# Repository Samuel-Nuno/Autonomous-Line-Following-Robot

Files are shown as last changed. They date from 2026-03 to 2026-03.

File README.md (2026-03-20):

# Autonomous-Line-Following-Robot
**Team Members:** Samuel Nuno, Bruce Berg

## Project Summary
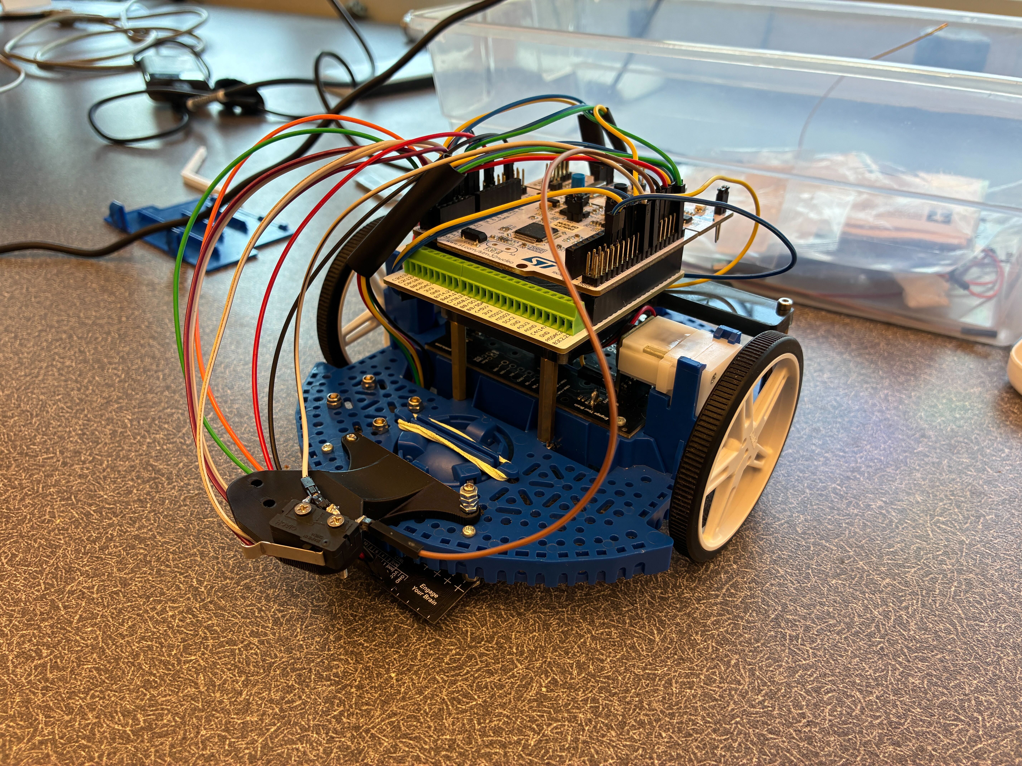
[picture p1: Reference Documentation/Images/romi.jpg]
Project Summary Image


This project documents our ME 405 [Romi](https://www.pololu.com/category/202/romi-chassis-and-accessories) final project, in which we developed a differential-drive robot capable of autonomous line following with closed-loop wheel control, line position estimation, and obstacle-triggered recovery behavior. The goal of the project was to create a robot that could reliably follow the printed course at speed while using organized, reproducible software and clear system documentation.

## Project Objective
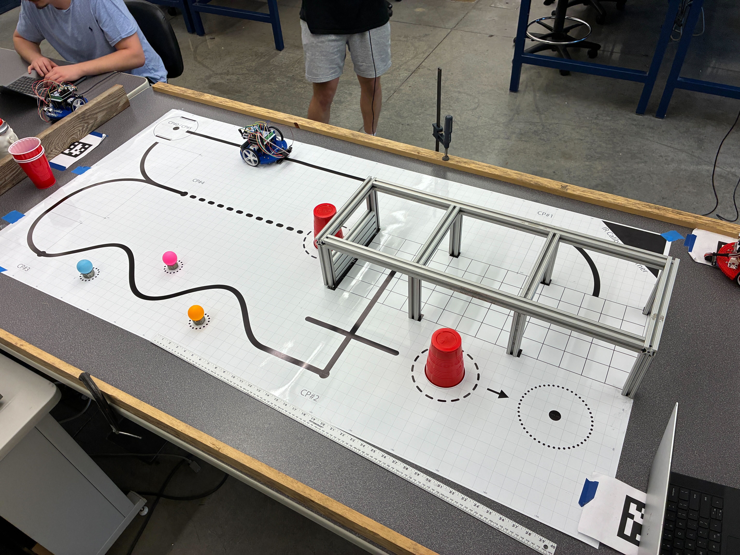
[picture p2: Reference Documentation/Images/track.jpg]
Project Objective Image


### Course Description
The course consists of four checkpoints. The starting point to the first checkpoint has a long straightaway where speed should be optimized. After Checkpoint 1, there is a right hand 90 degree turn into the garage, where there is no line to follow. Romi must navigate to the wall of the garage and, using a bump detection method, turn left to get back on the line. After the garage exit, there is a line perpendicular to the path out of the garage on which Romi may choose to turn left and bump a cup out of a position to reduce the overall time by 4 seconds. After the cup, Checkpoint 2 is reached. After Checkpoint 2, there is a slalom section, where Romi must make tight turns and avoid knocking ping pong balls out of position. If a ping pong ball is hit, a time penalty of 2 seconds is applied for each bumped ping pong ball. After the slalom section, Checkpoint 3 is reached. After Checkpoint 3, there is a large right hand turn into a cusp. At the end of the cusp, there is Checkpoint 4. After Checkpoint 4, there is a dotted line leading to an upsidedown cup, which, if knocked out of position, reduces the total time by 4 seconds. At the cusp, there is a turn that requires Romi to turn around and turn to the right to reach the finish line and complete the course.

### Our Approach to the Course
Our robot was designed to complete a line following time trial course by combining encoder based wheel feedback, analog line sensing, and task-based control software. The system was structured to prioritize repeatable behavior and robustness rather than relying on open-loop tuning alone.

We elected to avoid any of the additional bonus cups, since we evaluated that they would take too much time and development time to do reliably and fast enough to be worth it. We use our line following and specific events in our closed loop file that allow us to use line following along with hardcoded movements for the more dynamic movements which are triggered by events where the line is lost.

## Mechanical and Electrical Design
The platform is based on the Pololu Romi differential-drive chassis. The robot uses two independently driven wheels, each with its own motor and encoder feedback. In our preliminary design work, we identified several key chassis parameters that informed our control and sensing decisions, including a wheel radius of 35 mm and a track width of 141 mm.

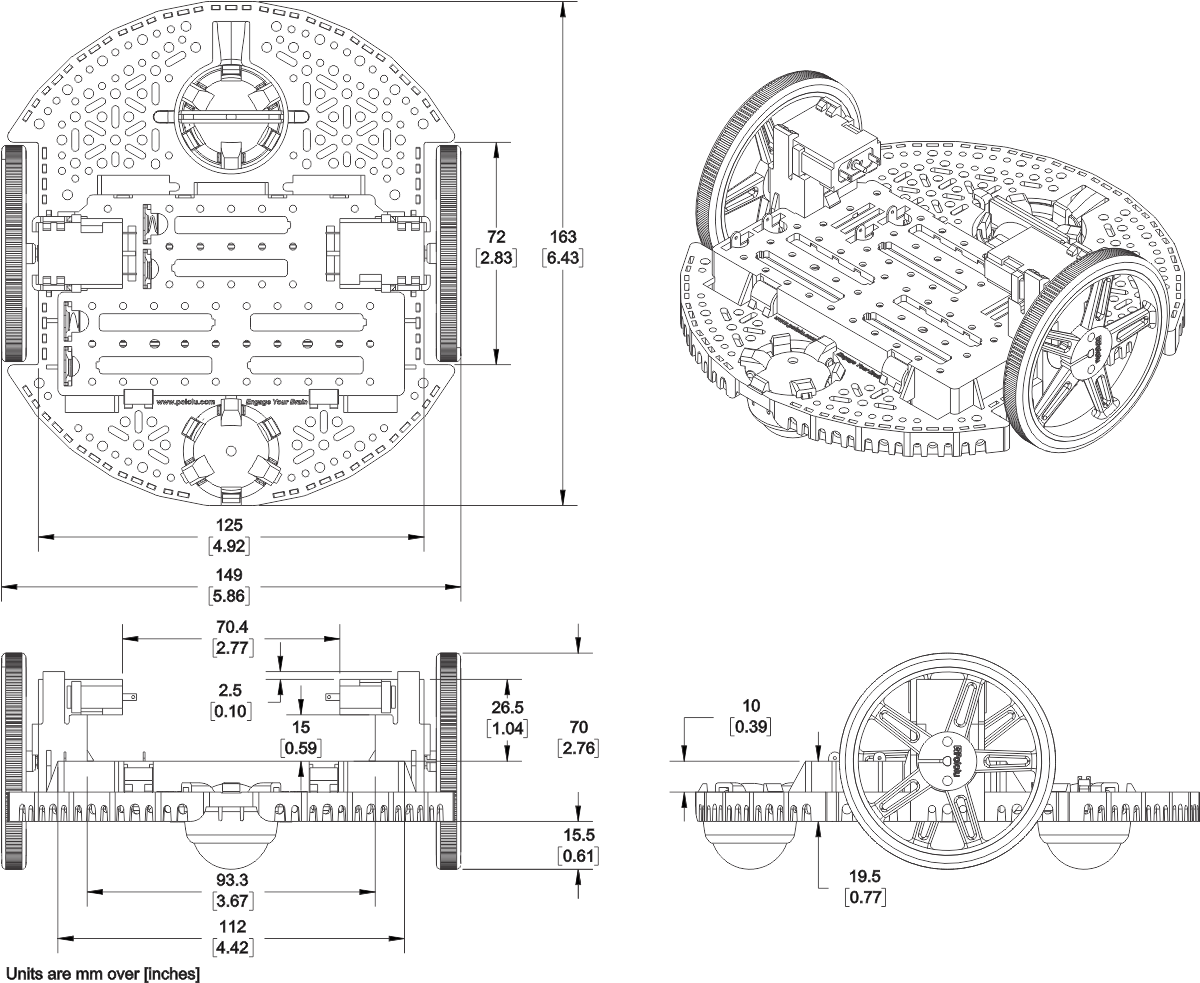
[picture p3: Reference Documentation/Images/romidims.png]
Romi Schematic


The electrical system includes:
- Two DC drive motors
- Wheel encoders for each side
- An STM32 microcontroller running MicroPython
- A Pololu QTR-8A analog reflectance sensor array for line following
- A bump sensor implemented as a single limit switch
- Motor driver outputs using PWM and direction pins

### Pinout Diagram
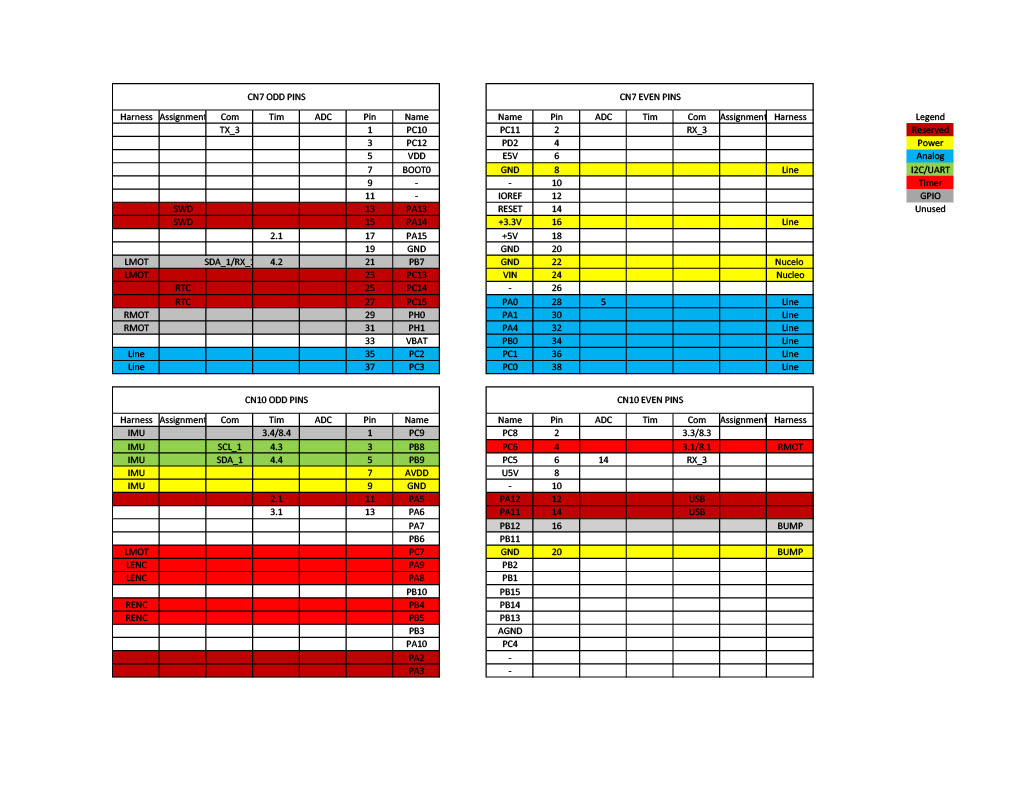
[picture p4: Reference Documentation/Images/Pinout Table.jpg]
Pinout Diagram


### Wiring Harnesses
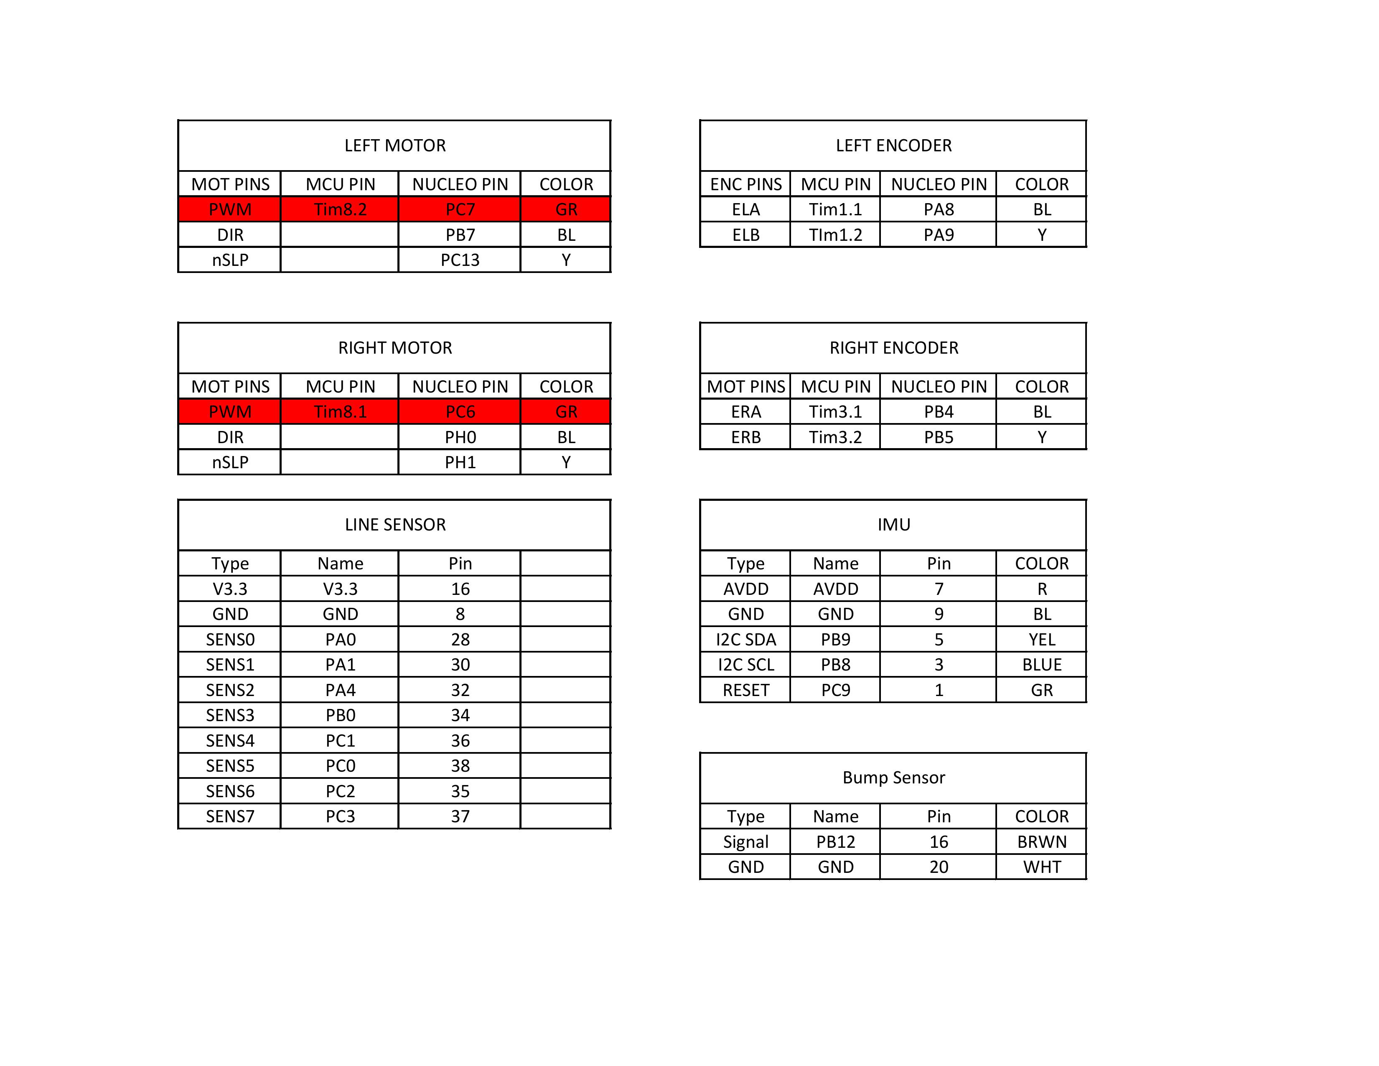
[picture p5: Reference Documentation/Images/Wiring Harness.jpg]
Harness Diagram


### Motor and Encoder Interface
Each motor is controlled by a PWM signal and a direction pin. Encoder feedback is used to estimate wheel speed and wheel position continuously.

## Sensors Used

### [Wheel Encoders](https://www.pololu.com/product/3675)
We used one quadrature encoder per wheel to estimate wheel position and velocity. In software, encoder counts are converted into wheel speed in mm/s.

### [Line Sensor Array](https://www.pololu.com/product/4248)
We selected an 8-channel analog Pololu QTR-MD-08A reflectance sensor array. An analog sensor array was chosen because it provides continuous reflectance measurements across all channels, allowing for more precise line position estimation and smoother control compared to digital threshold-based sensors.

The line sensor is calibrated on both white background and black line surfaces. After calibration, the readings from each channel are normalized, and a weighted centroid is computed (ranging from 0 to 7) to estimate the position of the line relative to the sensor array.

### [Bump Sensor](https://www.pololu.com/product/1405)
The bump sensor is implemented as a **single limit switch**. This provides a simple and reliable method of detecting contact with obstacles or walls, allowing the robot to trigger recovery behavior when pressed.

The bump sensor was mounted with a custom 3D printed part. The file can be found [here.](https://github.com/Samuel-Nuno/Autonomous-Line-Following-Robot/blob/main/Reference%20Documentation/Bump%20Sensor%20Mount.step)

### [IMU (Inertial Measurement Unit)](https://learn.adafruit.com/adafruit-bno055-absolute-orientation-sensor/overview)

The robot uses a BNO055 IMU to measure orientation, specifically the robot’s heading (yaw angle). The IMU provides absolute heading information, which allows the robot to understand its orientation relative to its starting direction.

Heading data is used primarily during recovery and maneuvering behaviors rather than continuous line following. When the robot performs actions such as turning 90 degrees or reorienting itself after losing the line, the IMU provides feedback to ensure accurate and repeatable rotations.

By monitoring the change in heading, the robot can:
- execute precise turns (e.g., 90° rotations),
- maintain consistent orientation during recovery sequences,
- and avoid relying solely on time-based or open-loop turning.

Using the IMU improves accuracy compared to open-loop turning because the robot can directly measure how far it has rotated rather than estimating based on motor commands alone.

## Software Architecture
The software is organized as a cooperative multitasking system using generators, scheduled by a priority-based task scheduler. Shared variables and queues are used for communication between tasks.

A thorough description of each file can be found in the Source Files section [here](https://github.com/Samuel-Nuno/Autonomous-Line-Following-Robot/tree/main/Source%20Code).

### Main software modules
- `main.py` initializes hardware, shares, queues, and tasks
- `cotask.py` implements cooperative task scheduling
- `task_share.py` implements inter-task shared data and queues
- `left_drive_system.py` and `right_drive_system.py` handle each motor/encoder pair
- `ClosedLoop.py` performs wheel PI control and line-following logic
- `task_line_sensor.py` reads the line sensor
- `linesensor.py` performs calibration, normalization, and centroid calculation
- `task_bump.py` handles bump detection
- `task_user.py` provides a serial tuning and diagnostics interface

## Control Strategy

### Closed-Loop Wheel Control
The robot uses PI control for left and right wheel velocity. Each wheel has a setpoint and measured velocity, and the controller computes motor effort from the wheel-speed error.

### Line Following
The line-following controller computes a centroid from the 8-sensor array, with the center target near sensor index 4. The line-following error is the difference between the measured centroid and the desired center.

The controller applies **PI control to the line-following error**, which allows smooth and continuous steering adjustments rather than abrupt corrections. A steering correction is applied by adjusting the left and right wheel velocities around a forward base speed.

This means:
- if the line appears to the left, the robot steers left,
- if the line appears to the right, the robot steers right,
- and if the line is centered, both wheels run at nearly equal speed.

## Lost-Line and Recovery Behavior
If the line sensor loses the line for several consecutive cycles, the robot begins a scripted recovery sequence. This sequence includes:
1. moving forward to square up,
2. moving farther into the garage area,
3. making a 90-degree right turn,
4. driving forward with encoder-based straightening,
5. then rotating left until the line is found again.

## Important Math and Parameters
Some important geometric and sensing values used in the project are:

- Wheel radius: **35 mm**
- Wheel diameter: **70 mm**
- Track width: **141 mm**
- Encoder resolution: **about 1430 to 1437 counts/rev**

A critical parameter in our implementation is the **conversion between encoder ticks and physical distance**. The relationship between encoder counts and linear distance is hard-coded in the software. This conversion factor determines how encoder measurements are translated into real-world units such as mm/s.

Because this value is fixed in the code, accuracy in the encoder ticks-per-unit-length conversion is essential. Any error in this parameter directly affects velocity estimation, distance tracking, and overall control performance.

## Video Demonstration
[Click Here](https://youtube.com/shorts/2tvsYlAGBHo?feature=share)

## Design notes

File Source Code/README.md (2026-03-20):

# ME405 Romi Robot Control System

## High Level Overview
This project implements a cooperative multitasking control system for a Romi robot using MicroPython. The robot uses multiple concurrent tasks to read sensors, control both motors, follow a line, and interact with the user through a serial interface.

At a high level, the system works as follows:
- The **main file** creates all shares, queues, and task objects
- The **drive system tasks** read encoders and apply motor effort
- The **closed loop task** performs PI velocity control and line-following logic
- The **line sensor task** computes the line centroid
- The **bump task** detects physical contact with an obstacle
- The **IMU heading task** reads robot heading and yaw rate
- The **user task** provides a serial command interface for tuning and testing
- The **ME405 cotask/task_share libraries** handle task scheduling and safe inter-task communication

This design separates sensing, control, and user interaction into modular finite state machines that communicate through shared variables and queues.

---

## Task Diagram
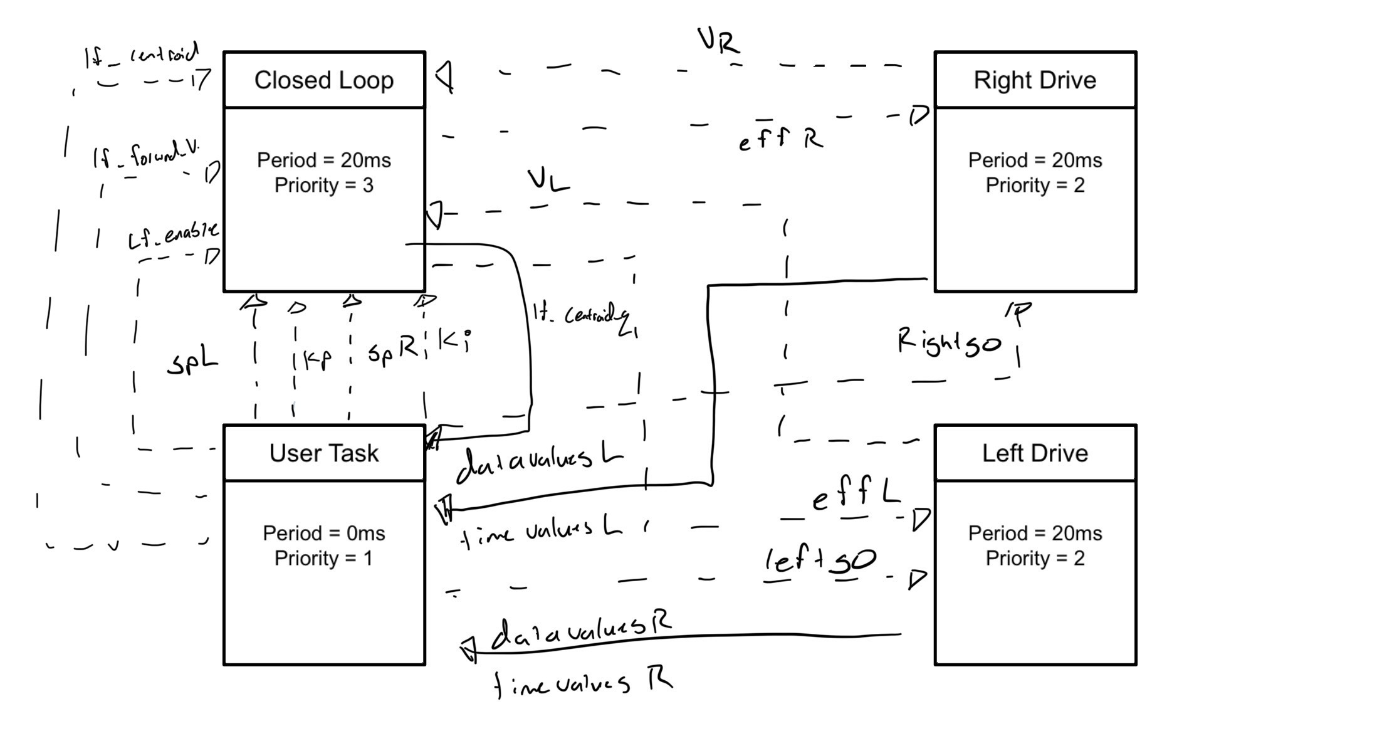
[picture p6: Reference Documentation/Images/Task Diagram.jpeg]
Insert task diagram image here


---

## Main File Overview
The `main.py` file is responsible for setting up the entire robot software system. It:
- Creates all shared variables (`Share`) and data buffers (`Queue`)
- Initializes default values such as gains, setpoints, and sensor outputs
- Creates each task object
- Adds each task to the scheduler with a priority and execution period
- Continuously runs the priority scheduler inside the main loop

The file defines shares for:
- left and right motor enable flags
- left and right velocity setpoints
- left and right measured velocities
- left and right encoder positions
- left and right control efforts
- PI controller gains
- line-following enable, speed, and centroid
- bump sensor state

The file also creates queues for logged time, velocity, and line centroid data. Once all tasks are created, they are appended to the task list and scheduled with `task_list.pri_sched()`.

---

# Tasks

## Left and Right drivesystem file

### Overview
The left and right drive system files implement the motor-side tasks for each wheel. These tasks are responsible for:
- reading the encoder every cycle
- computing wheel position and wheel velocity
- writing measured velocity to a shared variable
- writing encoder position to a shared variable
- reading the desired control effort from the closed-loop controller
- applying motor effort to the physical motor driver
- logging time and velocity data into queues for later display

These two files are nearly identical in structure, but they use different hardware pins and timers for the left and right motors.

### FSM
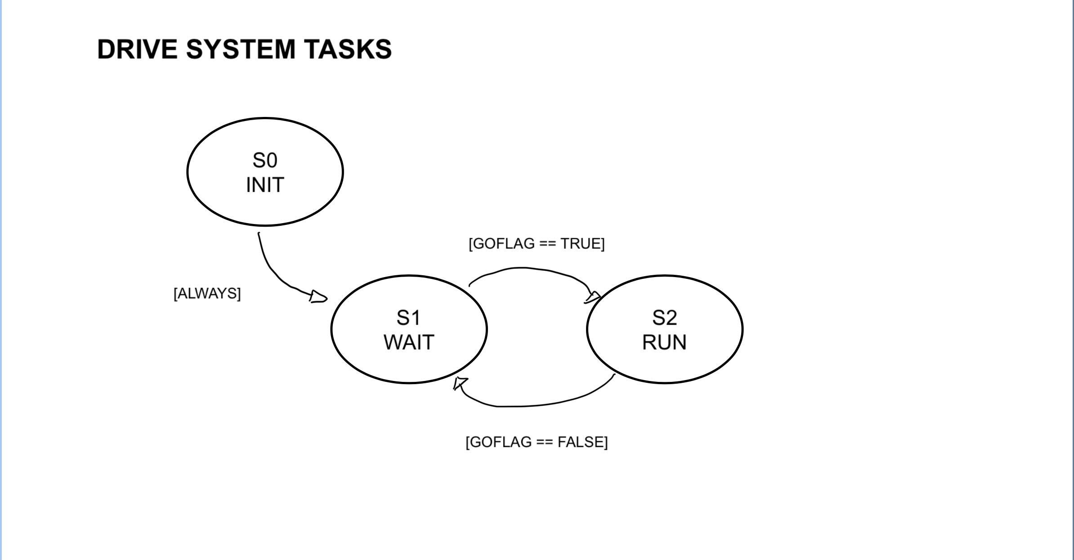
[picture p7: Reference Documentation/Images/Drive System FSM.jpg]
Insert Left/Right Drive System FSM image here


---

## Closed Loop file

### Overview
The `ClosedLoop.py` file contains the main controller for the robot. This task performs the closed-loop velocity control for both motors and also contains the higher-level line-following behavior.

Its main responsibilities are:
- reading left and right setpoints
- reading measured left and right wheel velocities
- computing velocity error for each wheel
- applying PI control to generate motor effort commands
- saturating the output effort to safe limits
- resetting integrators when setpoints change significantly
- supporting line-following operation by converting centroid error into left/right wheel setpoints
- handling lost-line behavior through a multi-step garage recovery script

When line following is enabled, the controller does not simply use externally supplied setpoints. Instead, it uses the line centroid and desired forward speed to generate left and right setpoints automatically. If the line is lost for long enough, the controller enters a scripted recovery routine that drives forward, turns, and searches for the line again.

### FSM
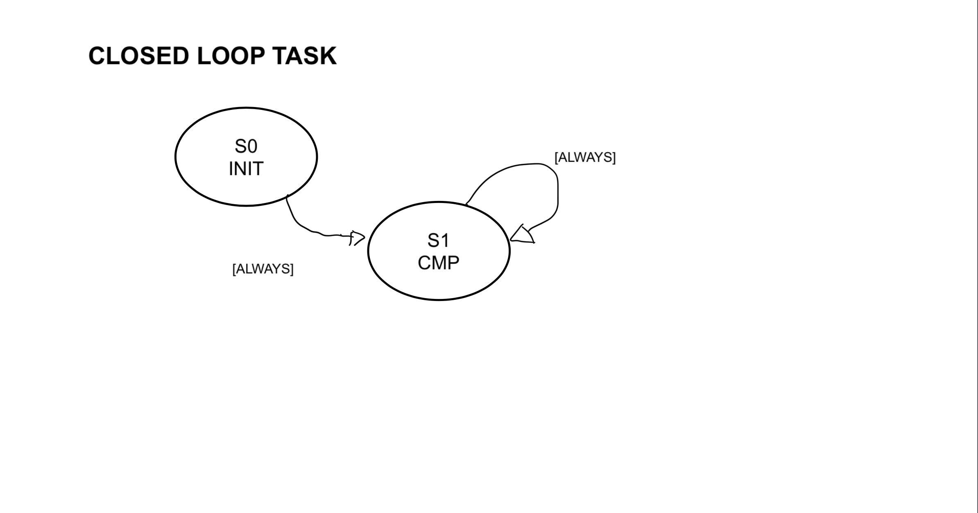
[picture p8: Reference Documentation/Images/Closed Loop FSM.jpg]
Insert Closed Loop FSM image here


---

## Task_User File

### Overview
The `task_user.py` file implements the user interface task. It communicates with a PC through USB serial and allows the user to interact with the robot at runtime.

This task allows the user to:
- print a help menu
- calibrate the line sensor on white and black surfaces
- set new proportional and integral gains
- set new left and right wheel setpoints
- enable or disable line following
- enter a line-following base velocity
- print raw and normalized line sensor values
- trigger a step response and print logged data
- emergency stop the robot
- print estimated pose values if estimator shares are connected
- reset pose values if an estimator task is connected

The user task is the main tuning and debugging interface for the robot.

### FSM
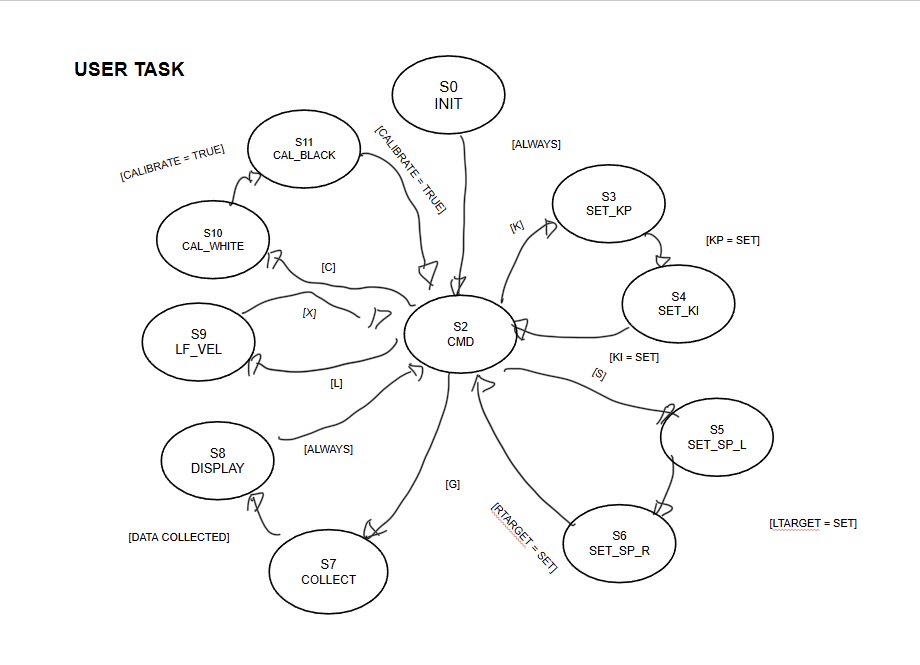
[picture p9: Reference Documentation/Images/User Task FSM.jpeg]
Insert Task_User FSM image here


---

## task_bump

### Overview
The `task_bump.py` file reads the bump sensor and publishes a debounced pressed/not-pressed result to a shared variable.

Its main responsibilities are:
- configuring the bump input pin
- handling either active-low or active-high wiring
- sampling the bump signal periodically
- debouncing the switch input over several samples
- publishing a stable bump state to a shared variable

The bump state is used by the closed-loop controller during garage recovery behavior.

### FSM
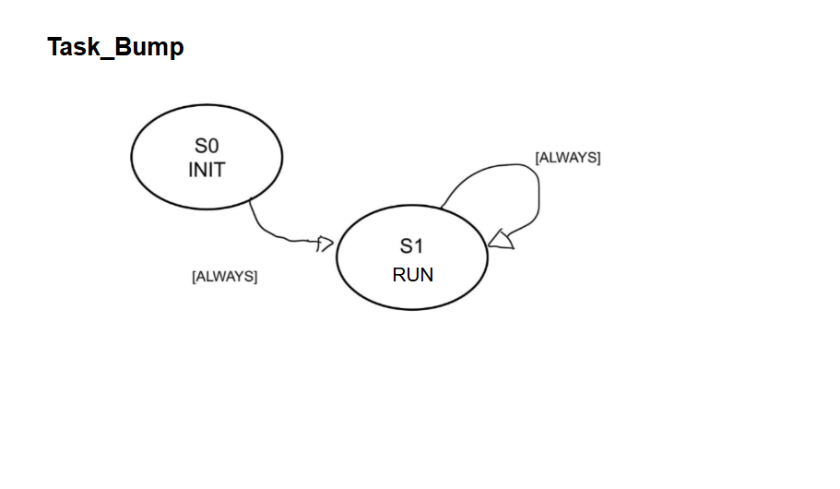
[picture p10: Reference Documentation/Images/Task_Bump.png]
Insert task_bump FSM image here


---

## task_imu_heading

### Overview
The `task_IMU_heading.py` file manages heading measurements from the BNO055 IMU. It initializes the IMU, stores a zero-heading reference, and continuously publishes heading and yaw rate.

Its main responsibilities are:
- initializing the I2C interface and IMU driver
- setting the BNO055 operating mode
- reading the absolute heading from the IMU
- subtracting the startup heading to create a relative heading
- reading yaw rate from the gyro
- writing heading and heading rate to shared variables
- allowing the heading reference to be reset

This task is useful for orientation measurement and future closed-loop heading control.

### FSM
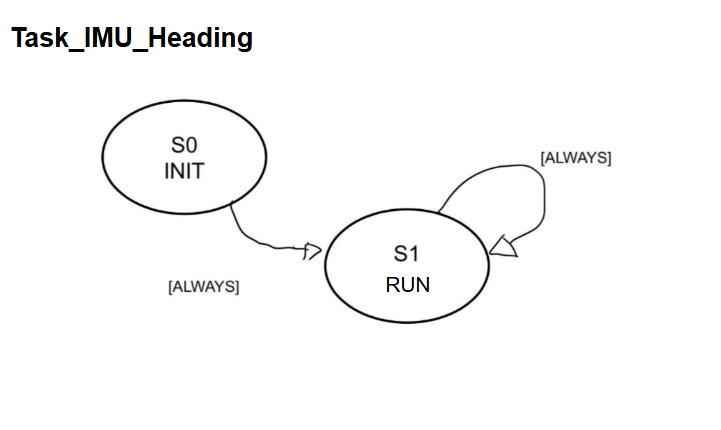
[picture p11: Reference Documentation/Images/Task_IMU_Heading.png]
Insert task_imu_heading FSM image here


---

## task_line_sensor

### Overview
The `task_line_sensor.py` file reads the 8-channel line sensor and computes the line centroid used for line following.

Its main responsibilities are:
- creating the line sensor driver object
- reading the line only when line following is enabled
- computing the centroid position from calibrated sensor values
- outputting a centroid value from 0 to 7 when a line is found
- outputting `-1.0` when no valid line is detected

This task isolates line detection from the main closed-loop controller and keeps the design modular.

### FSM
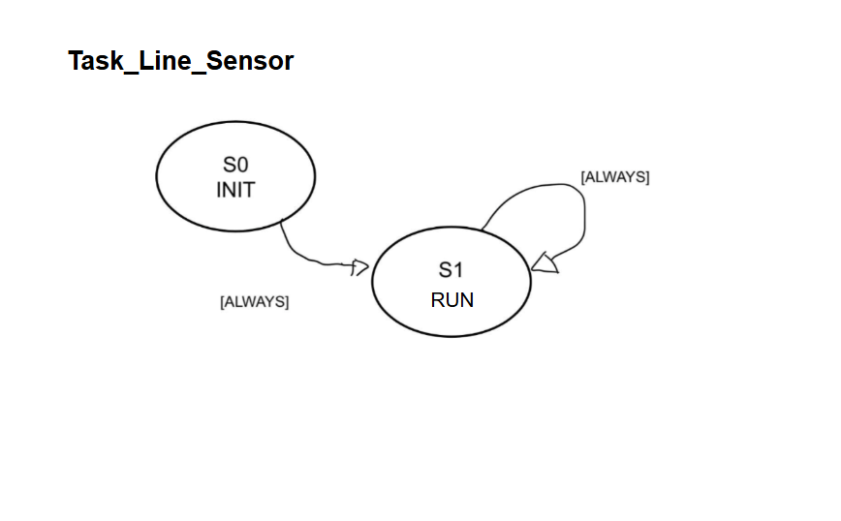
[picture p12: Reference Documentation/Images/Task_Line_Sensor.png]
Insert task_line_sensor FSM image here


---

# Drivers

## Encoder

### Overview
The `encoder.py` file implements a quadrature encoder interface. It uses a hardware timer in encoder mode to track wheel position and wheel speed.

### What it sets up
The encoder driver sets up:
- a hardware timer in encoder mode
- channel A and channel B encoder inputs
- internal variables for position, previous count, delta count, and elapsed time

### What data it takes in
The driver takes in:
- a timer number
- a pin for encoder channel A
- a pin for encoder channel B

### Methods
- `__init__(tim, chA_pin, chB_pin)`  
  Creates the encoder object, initializes the timer in encoder mode, and prepares all internal variables.

- `update()`  
  Reads the current timer count, computes the count difference since the last update, corrects for timer overflow, updates the cumulative position, and computes elapsed time.

- `get_position()`  
  Returns the total encoder position in counts.

- `get_velocity()`  
  Returns the wheel velocity in mm/s using the most recently computed count delta and elapsed time.

- `zero()`  
  Resets the position to zero and updates the internal reference count.

---

## Motor

### Overview
The `motor.py` file provides a motor driver interface for a DC motor driver that uses a PWM pin, a direction pin, and a sleep pin.

### What it sets up
The motor driver sets up:
- a PWM output pin
- a direction output pin
- a sleep/enable output pin
- a timer PWM channel for duty-cycle control

### What data it takes in
The driver takes in:
- PWM pin
- direction pin
- sleep pin
- timer object
- timer channel number
- requested motor effort from `-100` to `100`

### Methods
- `__init__(PWM, DIR, nSLP, tim, channel)`  
  Creates the motor object and configures the PWM, direction, and sleep pins.

- `set_effort(effort)`  
  Applies a signed effort command. Positive values drive in one direction, negative values drive in the opposite direction, and out-of-range values result in zero PWM.

- `enable()`  
  Wakes the motor driver from sleep mode and sets PWM output to zero.

- `disable()`  
  Puts the motor driver into sleep mode.

---

## linesensor

### Overview
The `linesensor.py` file provides a driver for the 8-channel Pololu QTR-MD-08A analog line sensor. It reads raw ADC values, normalizes them using calibration data, and computes a weighted centroid.

### What it sets up
The line sensor driver sets up:
- 8 ADC inputs
- white calibration values
- black calibration values
- sensor index positions from 0 to 7
- thresholds for line detection robustness

### What data it takes in
The driver takes in:
- a list of 8 ADC-capable pins

It also uses live ADC readings from each sensor channel.

### Methods
- `__init__(adc_pins)`  
  Creates ADC objects for all 8 sensors and initializes calibration data.

- `read_raw()`  
  Returns the raw ADC readings from all 8 sensors.

- `calibrate_white(n=50)`  
  Samples the sensor multiple times over a white surface and stores average white calibration values.

- `calibrate_black(n=50)`  
  Samples the sensor multiple times over a black line and stores average black calibration values.

- `norm_from_raw(raw)`  
  Converts raw readings into normalized values between 0 and 1 using calibration data.

- `read_norm()`  
  Reads raw sensor values and returns normalized values.

- `centroid_from_norm(w)`  
  Computes the weighted centroid from normalized sensor values. Returns `None` if no confident line is detected.

- `centroid()`  
  Performs a full raw read, normalization, and centroid computation in one step.

- `read_all()`  
  Returns raw values, normalized values, and centroid together for debugging.

---

## IMU_Driver

### Overview
The `IMU_Driver.py` file implements an I2C driver for the BNO055 inertial measurement unit. It supports heading, Euler angles, gyro data, calibration status, and saving/loading calibration constants.

### What it sets up
The IMU driver sets up:
- the I2C interface reference
- the IMU address
- an optional reset pin
- register-level communication helpers
- IMU operating mode and calibration functions

### What data it takes in
The driver takes in:
- a previously created I2C object
- an optional I2C address
- an optional reset pin

It reads data from:
- heading registers
- roll and pitch registers
- gyro registers
- calibration registers
- chip ID and configuration registers

### Methods
- `__init__(i2c, address=DEFAULT_ADDR, rst_pin=None)`  
  Creates the IMU driver object and stores references to the I2C bus and optional reset pin.

- `read_chip_id()`  
  Reads the BNO055 chip ID register.

- `hw_reset()`  
  Applies a hardware reset using the reset pin if one is connected.

- `set_mode(mode)`  
  Changes the BNO055 operating mode, such as IMU mode or NDOF mode.

- `get_calib_status()`  
  Returns the system, gyro, accelerometer, and magnetometer calibration status.

- `read_calibration_data()`  
  Reads the 22-byte calibration block from the IMU.

- `write_calibration_data(calib_bytes)`  
  Writes a 22-byte calibration block back to the IMU.

- `save_calibration_to_file(filename="bno055_calib.bin")`  
  Saves calibration bytes to a file.

- `load_calibration_from_file(filename="bno055_calib.bin")`  
  Loads calibration bytes from a file and writes them to the IMU.

- `read_euler()`  
  Returns heading, roll, and pitch in degrees.

- `read_heading()`  
  Returns just the heading in degrees.

- `read_gyro()`  
  Returns x, y, and z gyro rates in degrees per second.

- `read_yaw_rate_dps()`  
  Returns yaw rate in degrees per second.

- `read_yaw_rate_rads()`  
  Returns yaw rate in radians per second.

---

# [ME405 Library Files](https://github.com/spluttflob/ME405-Support)

## task_share

### Overview
The `task_share.py` file provides safe communication objects for sharing data between tasks. It contains two main classes:
- `Share` for a single shared value
- `Queue` for buffered FIFO data transfer

These classes are designed to reduce data corruption risk when tasks exchange data, especially when interrupts may be involved.

The file also maintains a system-wide list of all shares and queues for diagnostics.

---

## cotask

### Overview
The `cotask.py` file provides the cooperative multitasking framework used by the project.

Its main purpose is to:
- define tasks as generators
- allow tasks to yield control back to the scheduler
- schedule tasks based on period and priority
- support both round-robin and priority-based scheduling
- optionally profile execution timing
- optionally trace state transitions

The two main classes are:
- `Task` for representing an individual scheduled task
- `TaskList` for storing tasks and running the scheduler

This file is the foundation that allows all of the robot tasks to run together without a full RTOS.

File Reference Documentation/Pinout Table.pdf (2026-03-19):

Harness | Assignment | Com | Tim | ADC | Pin | Name | Name | Pin | ADC | Tim | Com | Assignment | Harness | Legend
| | TX_3 | | | 1 | PC10 | PC11 | 2 | | | RX_3 | | | Reserved
| | | | | 3 | PC12 | PD2 | 4 | | | | | | Power
| | | | | 5 | VDD | E5V | 6 | | | | | | Analog
| | | | | 7 | BOOT0 | GND | 8 | | | | | Line | I2C/UART
| | | | | 9 | - | - | 10 | | | | | | Timer
| | | | | 11 | - | IOREF | 12 | | | | | | GPIO
| SWD | | | | 13 | PA13 | RESET | 14 | | | | | | Unused
| SWD | | | | 15 | PA14 | +3.3V | 16 | | | | | Line
| | | 2.1 | | 17 | PA15 | +5V | 18
| | | | | 19 | GND | GND | 20
LMOT | SDA_1/RX_1 | 4.2 | 21 | PB7 | GND | 22 | Nucelo
LMOT | | | | | 23 | PC13 | VIN | 24 | | | | | Nucleo
| RTC | | | | 25 | PC14 | - | 26
| RTC | | | | 27 | PC15 | PA0 | 28 | 5 | | | | Line
RMOT | | | | | 29 | PH0 | PA1 | 30 | | | | | Line
RMOT | | | | | 31 | PH1 | PA4 | 32 | | | | | Line
| | | | | 33 | VBAT | PB0 | 34 | | | | | Line
Line | | | | | 35 | PC2 | PC1 | 36 | | | | | Line
Line | | | | | 37 | PC3 | PC0 | 38 | | | | | Line
Harness | Assignment | Com | Tim | ADC | Pin | Name | Name | Pin | ADC | Tim | Com | Assignment | Harness
IMU | | | 3.4/8.4 | | 1 | PC9 | PC8 | 2 | | | 3.3/8.3
IMU | | SCL_1 | 4.3 | | 3 | PB8 | PC6 | 4 | | | 3.1/8.1 | | RMOT
IMU | | SDA_1 | 4.4 | | 5 | PB9 | PC5 | 6 | 14 | | RX_3
IMU | | | | | 7 | AVDD | U5V | 8
IMU | | | | | 9 | GND | - | 10
| | | 2.1 | | 11 | PA5 | PA12 | 12 | | | USB
| | | 3.1 | | 13 | PA6 | PA11 | 14 | | | USB
| | | | | | PA7 | PB12 | 16 | | | | | BUMP
| | | | | | PB6 | PB11
LMOT | | | | | | PC7 | GND | 20 | | | | | BUMP
LENC | | | | | | PA9 | PB2
LENC | | | | | | PA8 | PB1
| | | | | | PB10 | PB15
RENC | | | | | | PB4 | PB14
RENC | | | | | | PB5 | PB13
| | | | | | PB3 | AGND
| | | | | | PA10 | PC4
| | | | | | PA2 | -
| | | | | | PA3 | -
CN7 ODD PINS | CN7 EVEN PINS
CN10 ODD PINS | CN10 EVEN PINS

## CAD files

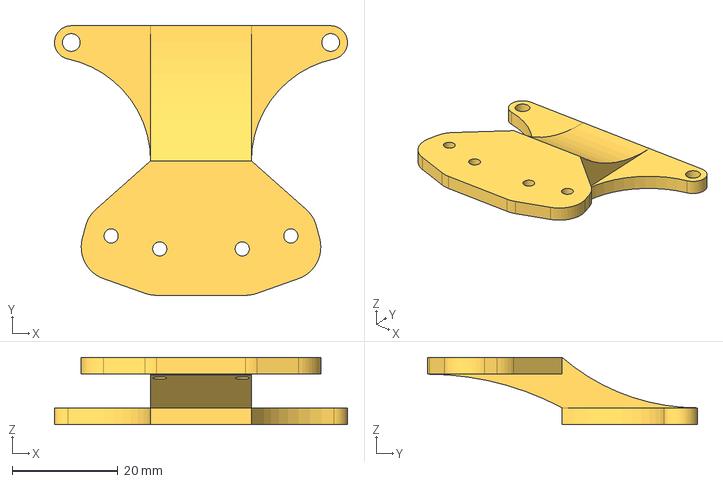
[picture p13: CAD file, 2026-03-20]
Reference Documentation/Bump Sensor Mount.step
55.3 x 50.9 x 12.7 mm

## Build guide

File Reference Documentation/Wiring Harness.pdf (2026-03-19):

MOT PINS | MCU PIN | NUCLEO PIN | COLOR | ENC PINS | MCU PIN | NUCLEO PIN | COLOR
PWM | Tim8.2 | PC7 | GR | ELA | Tim1.1 | PA8 | BL
DIR | | PB7 | BL | ELB | TIm1.2 | PA9 | Y
nSLP | | PC13 | Y
MOT PINS | MCU PIN | NUCLEO PIN | COLOR | MOT PINS | MCU PIN | NUCLEO PIN | COLOR
PWM | Tim8.1 | PC6 | GR | ERA | Tim3.1 | PB4 | BL
DIR | | PH0 | BL | ERB | Tim3.2 | PB5 | Y
nSLP | | PH1 | Y
Type | Name | Pin | Type | Name | Pin | COLOR
V3.3 | V3.3 | 16 | AVDD | AVDD | 7 | R
GND | GND | 8 | GND | GND | 9 | BL
SENS0 | PA0 | 28 | I2C SDA | PB9 | 5 | YEL
SENS1 | PA1 | 30 | I2C SCL | PB8 | 3 | BLUE
SENS2 | PA4 | 32 | RESET | PC9 | 1 | GR
SENS3 | PB0 | 34
SENS4 | PC1 | 36
SENS5 | PC0 | 38
SENS6 | PC2 | 35
SENS7 | PC3 | 37 | Type | Name | Pin | COLOR
Signal | PB12 | 16 | BRWN
GND | GND | 20 | WHT

Bump Sensor

LEFT MOTOR

RIGHT MOTOR

LEFT ENCODER

RIGHT ENCODER

LINE SENSOR | IMU

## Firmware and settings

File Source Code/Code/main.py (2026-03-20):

from pyb import Timer
from pyb import Pin
import utime
from task_share import Share, Queue, show_all
from cotask import Task, task_list
from gc import collect

from task_line_sensor import task_line_sensor
from linesensor import linesensor
from task_bump import task_bump

from ClosedLoop import Closed_Loop
from task_user import task_user

from left_drive_system import task_left_drive
from right_drive_system import task_right_drive
from task_start_button import task_start_button

# PWM timer (both motors on Timer 8)
tim_pwm = Timer(8, freq=20000)

# Shares
leftMotorGo  = Share("B", name="Left Go")
rightMotorGo = Share("B", name="Right Go")

spL = Share("f", name="Setpoint L")
spR = Share("f", name="Setpoint R")

vL = Share("f", name="Velocity L")
vR = Share("f", name="Velocity R")

# NEW: encoder position shares
posL = Share("l", name="Position L")
posR = Share("l", name="Position R")

effL = Share("h", name="Effort L")
effR = Share("h", name="Effort R")

Kp = Share("f", name="Kp")
Ki = Share("f", name="Ki")

# Stronger defaults so it actually moves
Kp.put(0.2)
Ki.put(0)

# Line following shares
lf_enable   = Share("B", name="LF Enable")
lf_forwardV = Share("f", name="LF Forward Vel")
lf_centroid = Share("f", name="LF Centroid")
bump_pressed = Share("B", name="Bump Pressed")

# defaults
lf_enable.put(0)
lf_forwardV.put(250.0)
leftMotorGo.put(0)
rightMotorGo.put(0)
spL.put(0)
spR.put(0)
effL.put(0)
effR.put(0)
lf_centroid.put(-1.0)
bump_pressed.put(0)
posL.put(0)
posR.put(0)

# Queues
# Keep moderate to avoid RAM trouble
N_SAMPLES = 100
N_CENTROID_SAMPLES = 100
dataValuesL = Queue("f", N_SAMPLES, name="Left Velocity Buffer")
dataValuesR = Queue("f", N_SAMPLES, name="Right Velocity Buffer")
timeValuesL = Queue("L", N_SAMPLES, name="Left Time Buffer")
timeValuesR = Queue("L", N_SAMPLES, name="Right Time Buffer")
lf_centroid_q = Queue("f", N_CENTROID_SAMPLES, name="Centroid Buffer")

# Tasks
leftTask = task_left_drive(
    tim_pwm, leftMotorGo, effL, vL, dataValuesL, timeValuesL,
    posL_share=posL,
    lf_centroid_share=lf_centroid,
    lf_centroid_queue=lf_centroid_q
)

rightTask = task_right_drive(
    tim_pwm, rightMotorGo, effR, vR, dataValuesR, timeValuesR,
    posR_share=posR
)

ctrlTask = Closed_Loop(
    spL, spR, vL, vR, effL, effR, Kp, Ki,
    lf_enable_share=lf_enable,
    lf_v_share=lf_forwardV,
    lf_centroid_share=lf_centroid,
    bump_share=bump_pressed,
    posL_share=posL,
    posR_share=posR,
    lf_deadband=0.4,
    lf_dv_turn=180,
    lf_lost_val=-1
)

# Line sensor task
qtr_adc_pins = [
    Pin.cpu.A0,
    Pin.cpu.A1,
    Pin.cpu.A4,
    Pin.cpu.B0,
    Pin.cpu.C1,
    Pin.cpu.C0,
    Pin.cpu.C2,
    Pin.cpu.C3,
]
lineTask = task_line_sensor(qtr_adc_pins, lf_centroid, lf_enable)

bumpTask = task_bump(bump_pressed, pin=Pin.cpu.B12, active_low=True, debounce_count=3)

uiTask = task_user(
    leftMotorGo, rightMotorGo,
    spL, spR,
    effL, effR,
    dataValuesL, dataValuesR,
    timeValuesL, timeValuesR,
    Kp_share=Kp,
    Ki_share=Ki,
    lf_enable_share=lf_enable,
    lf_v_share=lf_forwardV,
    lf_centroid_queue=lf_centroid_q,
    sensor=lineTask.sensor,
)

startTask = task_start_button(
    leftMotorGo,
    rightMotorGo,
    lf_enable=lf_enable,
    lf_v_share=lf_forwardV,
    effL=effL,
    effR=effR,
    spL=spL,
    spR=spR,
    start_speed=220.0
)

# Scheduler
task_list.append(Task(leftTask.run,  name="Left Drive",  priority=2, period=20, profile=False))
task_list.append(Task(rightTask.run, name="Right Drive", priority=2, period=20, profile=False))
task_list.append(Task(ctrlTask.run,  name="Closed Loop", priority=3, period=20, profile=False))
task_list.append(Task(lineTask.run,  name="Line Sensor", priority=2, period=20, profile=False))
task_list.append(Task(bumpTask.run,  name="Bump",        priority=2, period=10, profile=False))
task_list.append(Task(uiTask.run,    name="User UI",     priority=1, period=0,  profile=False))
task_list.append(Task(startTask.run, name="Start Button", priority=1, period=50, profile=False))

collect()

while True:
    try:
        task_list.pri_sched()
    except KeyboardInterrupt:
        print("Program Terminating")
        break

print(task_list)

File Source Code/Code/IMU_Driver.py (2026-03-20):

from pyb import I2C, Pin
import utime


class IMU_Driver:
    """
    BNO055 IMU Driver (I2C)
    - Read chip ID
    - Set fusion mode (IMU / NDOF)
    - Read calibration status
    - Read Euler angles (heading/roll/pitch)
    - Read gyro (angular rate) including yaw rate
    - Read/write calibration coefficients (offsets/radii) for saving/loading
    """

    # I2C Address
    DEFAULT_ADDR = 0x28  # BNO055 default I2C addr (ADR pin low)

    # Core registers
    REG_CHIP_ID   = 0x00
    REG_PAGE_ID   = 0x07

    REG_OPR_MODE  = 0x3D
    REG_PWR_MODE  = 0x3E
    REG_SYS_TRIGGER = 0x3F

    REG_CALIB_STAT = 0x35

    # Operating modes
    MODE_CONFIG = 0x00
    MODE_IMU    = 0x08   # accel+gyro fusion
    MODE_NDOF   = 0x0C   # full fusion (accel+gyro+mag)

    # Power modes
    PWR_NORMAL  = 0x00

    # Euler registers (Page 0, little-endian)
    # 1 deg = 16 LSB
    REG_EUL_HEADING_LSB = 0x1A
    REG_EUL_ROLL_LSB    = 0x1C
    REG_EUL_PITCH_LSB   = 0x1E

    # Gyro registers (Page 0, little-endian)
    # Units: 1 dps = 16 LSB
    REG_GYR_DATA_X_LSB  = 0x14
    # x: 0x14-0x15, y: 0x16-0x17, z: 0x18-0x19

    # Calibration data block (Page 0)
    # Offsets + radii total = 22 bytes starting at 0x55
    REG_CALIB_DATA_START = 0x55
    CALIB_DATA_LEN       = 22

    def __init__(self, i2c, address=DEFAULT_ADDR, rst_pin=None):
        """
        Args:
            i2c: pre-created pyb.I2C object
            address: I2C address (0x28 usually)
            rst_pin: optional pyb.Pin for hardware reset (your table: PC9)
        """
        self._i2c = i2c
        self._addr = address
        self._rst = rst_pin

        utime.sleep_ms(50)  # power-up delay

    # Low-level helpers
    def _read_bytes(self, start_reg, length):
        buf = bytearray(length)
        self._i2c.mem_read(buf, self._addr, start_reg)
        return buf

    def _write_byte(self, reg, val):
        self._i2c.mem_write(val & 0xFF, self._addr, reg)

    def _set_page(self, page):
        self._write_byte(self.REG_PAGE_ID, page & 0x01)
        utime.sleep_ms(2)

    def _bytes_to_int16(self, lsb, msb):
        val = (msb << 8) | lsb
        if val & 0x8000:
            val -= 0x10000
        return val

    # Basic ID / reset / mode
    def read_chip_id(self):
        return self._read_bytes(self.REG_CHIP_ID, 1)[0]

    def hw_reset(self):
        """
        Optional hardware reset if you wired RESET to PC9 (your table shows PC9).
        If you didn't wire reset, you can ignore this.
        """
        if self._rst is None:
            return

        # Active low reset
        self._rst.low()
        utime.sleep_ms(10)
        self._rst.high()
        utime.sleep_ms(650)  # datasheet recommends ~650ms after reset

    def set_mode(self, mode):
        """
        Always switch to CONFIG mode before changing modes (BNO055 requirement).
        """
        self._set_page(0)
        self._write_byte(self.REG_OPR_MODE, self.MODE_CONFIG)
        utime.sleep_ms(25)

        self._write_byte(self.REG_PWR_MODE, self.PWR_NORMAL)
        utime.sleep_ms(10)

        self._write_byte(self.REG_OPR_MODE, mode)
        utime.sleep_ms(25)

    # Calibration
    def get_calib_status(self):
        """
        Returns tuple: (sys, gyro, acc, mag) where each is 0..3
        """
        raw = self._read_bytes(self.REG_CALIB_STAT, 1)[0]
        sys_cal  = (raw >> 6) & 0b11
        gyro_cal = (raw >> 4) & 0b11
        acc_cal  = (raw >> 2) & 0b11
        mag_cal  = (raw >> 0) & 0b11
        return (sys_cal, gyro_cal, acc_cal, mag_cal)

    def read_calibration_data(self):
        self._set_page(0)

        prev_mode = self._read_bytes(self.REG_OPR_MODE, 1)[0]

        self._write_byte(self.REG_OPR_MODE, self.MODE_CONFIG)
        utime.sleep_ms(25)

        data = self._read_bytes(self.REG_CALIB_DATA_START, self.CALIB_DATA_LEN)

        self._write_byte(self.REG_OPR_MODE, prev_mode)
        utime.sleep_ms(25)

        return bytes(data)

    def write_calibration_data(self, calib_bytes):
        if calib_bytes is None or len(calib_bytes) != self.CALIB_DATA_LEN:
            raise ValueError("calib_bytes must be exactly 22 bytes")

        self._set_page(0)
        prev_mode = self._read_bytes(self.REG_OPR_MODE, 1)[0]

        self._write_byte(self.REG_OPR_MODE, self.MODE_CONFIG)
        utime.sleep_ms(25)

        self._i2c.mem_write(bytearray(calib_bytes), self._addr, self.REG_CALIB_DATA_START)
        utime.sleep_ms(10)

        self._write_byte(self.REG_OPR_MODE, prev_mode)
        utime.sleep_ms(25)

    def save_calibration_to_file(self, filename="bno055_calib.bin"):
        """
        Convenience helper for MicroPython filesystem.
        """
        data = self.read_calibration_data()
        with open(filename, "wb") as f:
            f.write(data)

    def load_calibration_from_file(self, filename="bno055_calib.bin"):
        """
        Convenience helper for MicroPython filesystem.
        """
        with open(filename, "rb") as f:
            data = f.read()
        self.write_calibration_data(data)

    # Euler angles
    def read_euler(self):
        """
        Returns (heading_deg, roll_deg, pitch_deg)
        Scaling: 1 deg = 16 LSB
        """
        self._set_page(0)
        buf = self._read_bytes(self.REG_EUL_HEADING_LSB, 6)

        heading_raw = self._bytes_to_int16(buf[0], buf[1])
        roll_raw    = self._bytes_to_int16(buf[2], buf[3])
        pitch_raw   = self._bytes_to_int16(buf[4], buf[5])

        return (heading_raw / 16.0, roll_raw / 16.0, pitch_raw / 16.0)

    def read_heading(self):
        h, _, _ = self.read_euler()
        return h

    # Gyro (angular rates)
    def read_gyro(self):
        """
        Returns (gx_dps, gy_dps, gz_dps)
        Scaling: 1 dps = 16 LSB
        """
        self._set_page(0)
        buf = self._read_bytes(self.REG_GYR_DATA_X_LSB, 6)

        gx_raw = self._bytes_to_int16(buf[0], buf[1])
        gy_raw = self._bytes_to_int16(buf[2], buf[3])
        gz_raw = self._bytes_to_int16(buf[4], buf[5])

        return (gx_raw / 16.0, gy_raw / 16.0, gz_raw / 16.0)

    def read_yaw_rate_dps(self):
        """
        Returns yaw rate (gyro Z) in deg/s.
        """
        _, _, gz = self.read_gyro()
        return gz

    def read_yaw_rate_rads(self):
        """
        Returns yaw rate (gyro Z) in rad/s (often nicer for controls later).
        """
        gz_dps = self.read_yaw_rate_dps()
        return gz_dps * 3.141592653589793 / 180.0

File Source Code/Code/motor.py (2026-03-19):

from pyb import Pin, Timer

class Motor:
    '''A motor driver interface encapsulated in a Python class. Works with
       motor drivers using separate PWM and direction inputs such as the DRV8838
       drivers present on the Romi chassis from Pololu.'''
    
    def __init__(self, PWM, DIR, nSLP, tim, channel):
        '''Initializes a Motor object'''
        self.PWM_pin = Pin(PWM, mode=Pin.OUT_PP, value=0)
        self.DIR_pin = Pin(DIR, mode=Pin.OUT_PP, value=0)
        self.nSLP_pin = Pin(nSLP, mode=Pin.OUT_PP, value=0)
        self.PWM_chan = tim.channel(channel, pin=PWM, mode=Timer.PWM, pulse_width_percent=0)

    def set_effort(self, effort):
        '''Sets the present effort requested from the motor based on an input value
           between -100 and 100'''
        if effort <= 100 and effort > 0:
            self.DIR_pin.low()
            self.PWM_chan.pulse_width_percent(effort)
        elif effort >= -100 and effort < 0:
            self.DIR_pin.high()
            self.PWM_chan.pulse_width_percent(-effort)
        else:
            self.PWM_chan.pulse_width_percent(0)  
            
    def enable(self):
        '''Enables the motor driver by taking it out of sleep mode into brake mode'''
        self.nSLP_pin.high()
        self.PWM_chan.pulse_width_percent(0)
            
    def disable(self):
        '''Disables the motor driver by taking it into sleep mode'''
        self.nSLP_pin.low()

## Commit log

2026-03-09 Create Track Description
2026-03-19 Rename Source Code/IMU_Driver.py to Source Code/Code/IMU_Driver.py
2026-03-19 Rename Source Code/encoder.py to Source Code/Code/encoder.py
2026-03-19 Rename Source Code/motor.py to Source Code/Code/motor.py
